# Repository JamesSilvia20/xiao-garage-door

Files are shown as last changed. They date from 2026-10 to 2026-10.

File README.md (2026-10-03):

# XIAO Garage Door 🚗🏠

**Make your garage door opener smart for about $10 in parts.** This is a tiny open-source board that holds a [Seeed Studio XIAO ESP32-C6](https://www.seeedstudio.com/Seeed-Studio-XIAO-ESP32C6-p-5884.html) and wires to your opener's wall-button terminals. You can then open and close your garage from **Home Assistant**, **Apple Home** (with Siri and automations), or anything else that talks to [ESPHome](https://esphome.io).

No cloud, no subscription, no app from the opener company. Everything runs on your own network.

<p align="center">
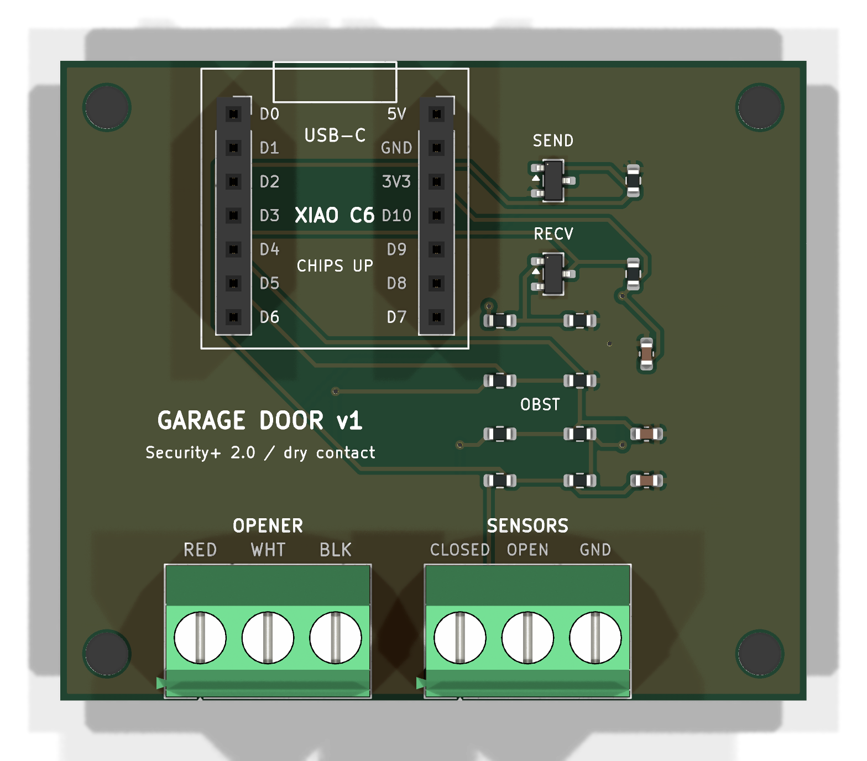
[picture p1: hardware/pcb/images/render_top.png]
XIAO Garage Door PCB
  
</p>

## What it does

| Your opener | What you get |
|---|---|
| **Security+ 2.0** (LiftMaster / Chamberlain / Craftsman with a **yellow** learn button, the myQ kind) | Real open / closed / opening / closing status, light, lock, obstruction alerts and motion, read straight from the opener. |
| **Security+ 1.0** (same brands, **purple / red / orange** learn button) | Same as above. |
| **Any opener with a simple 2-wire wall button** (most other brands, older units) | Open / close / stop from your phone. Add a $5 magnetic reed switch for true open/closed status. |

One board does all of these. You pick the matching firmware.

## Start here 👇

New to this? Follow the guides in order. They're written for complete beginners, and we explain every step.

1. 🔍 [**Which opener do I have?**](docs/start/which-opener.md): pick your firmware in 2 minutes.
2. 🛒 [**Parts and cost**](docs/start/parts.md): everything you need, with links.
3. ⚠️ [**Safety first**](docs/start/safety.md): please read this one.
4. 🔧 Get the hardware, either way:
   - [**Order the ready-made PCB**](docs/hardware/order-pcb.md) from JLCPCB or PCBWay, all parts soldered for you, about $25–40 for 5 boards; **or**
   - [**Build it on perfboard**](docs/hardware/perfboard.md) with a few cheap parts (new to soldering? see [**Soldering 101**](docs/hardware/soldering-101.md)).
5. ⚡ [**Flash the firmware**](docs/setup/flash.md): straight from your web browser, no software to install.
6. 🏠 [**Add to Home Assistant**](docs/setup/home-assistant.md) and [**Apple Home**](docs/setup/apple-home.md).
7. 🪛 [**Install it at the opener**](docs/setup/install.md).

Stuck? See [**Troubleshooting**](docs/help/troubleshooting.md) and the [**FAQ**](docs/help/faq.md).

> [!TIP]
> Prefer a website? The same guides are at **https://jamessilvia20.github.io/xiao-garage-door/**, and that's where the one-click **browser installer** lives.

## What's in this repo

```
firmware/        ESPHome configs (one per opener type) - flash from the browser or adopt in ESPHome
hardware/pcb/    The PCB: KiCad board, scripts that build it, and ready-to-upload JLCPCB / PCBWay files
docs/            All the tutorials (this is also the website)
```

## Project status

Honest status, so you know what's been tested:

| Part | Status |
|---|---|
| Dry-contact firmware + hand-built perfboard | ✅ Built and bench-tested by the author (switches the wall-button contacts on command, shows up in HA and Apple Home). |
| Security+ 2.0 / 1.0 firmware | ✅ Compiles for the XIAO C6, using the proven [esphome-ratgdo](https://github.com/ratgdo/esphome-ratgdo) component and the community [rat-ratgdo](https://github.com/Kaldek/rat-ratgdo) circuit. 🧪 Not yet tested by the author on this exact board. Reports welcome! |
| PCB v1 | 🧪 Design passes KiCad DRC with 0 errors, and the JLCPCB/PCBWay files are generated. First boards are on order. |

Built one? Please open an issue or discussion with how it went (photos welcome!), so we can turn the 🧪s into ✅s.

## Credits

This stands on the shoulders of [**ratgdo**](https://github.com/ratgdo) (Paul Wieland and contributors), [**rat-ratgdo**](https://github.com/Kaldek/rat-ratgdo), [**esphome-ratgdo**](https://github.com/ratgdo/esphome-ratgdo), [**ESPHome**](https://esphome.io) and [**Home Assistant**](https://www.home-assistant.io). If you want a polished, ready-made product, buy an official [ratgdo](https://ratcloud.llc). It's great and supports the people who figured all this out.

See [Credits and license](docs/makers/credits.md).

## License

[MIT](LICENSE) for everything in this repo (firmware configs, PCB, docs). The Security+ firmware pulls in esphome-ratgdo, which is GPL-2.0.

> [!WARNING]
> Garage doors are heavy and can hurt people. Keep your photo-eye safety sensors connected and working. Never close the door remotely unless you can be sure nobody is under it. See [Safety first](docs/start/safety.md).

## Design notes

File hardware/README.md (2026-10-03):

# Hardware

| Folder | What's inside |
|---|---|
| [`pcb/jlcpcb/`](pcb/jlcpcb) | Ready-to-upload JLCPCB files: Gerbers zip, BOM, CPL |
| [`pcb/pcbway/`](pcb/pcbway) | PCBWay files: Gerbers zip, BOM (manufacturer part numbers), centroid |
| [`pcb/source/`](pcb/source) | KiCad board + the Python scripts that generate, route and check it |
| [`pcb/images/`](pcb/images) | Renders |

**Guides:** [Order the PCB](../docs/hardware/order-pcb.md) · [Build on perfboard](../docs/hardware/perfboard.md) · [How the circuit works](../docs/hardware/circuit.md) · [Edit the PCB](../docs/makers/edit-pcb.md)

PCB

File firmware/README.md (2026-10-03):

# Firmware

ESPHome configs for the Seeed XIAO ESP32-C6 on the XIAO Garage Door board (or the perfboard build).

| Config | Opener |
|---|---|
| [`garage-secplus2.yaml`](garage-secplus2.yaml) | Security+ 2.0, yellow learn button (myQ) |
| [`garage-secplus1.yaml`](garage-secplus1.yaml) | Security+ 1.0, purple / red / orange learn button |
| [`garage-dry-contact.yaml`](garage-dry-contact.yaml) | Simple 2-wire wall button, no sensor (assumed state) |
| [`garage-dry-contact-sensor.yaml`](garage-dry-contact-sensor.yaml) | Simple 2-wire wall button + reed switch (real state) |

No Wi-Fi passwords or keys are baked in. Set Wi-Fi with the browser installer (Improv) or the "Garage Door Setup" hotspot.

**Flash:** see [Flash the firmware](../docs/setup/flash.md). **Reference:** [Firmware reference](../docs/makers/firmware.md).

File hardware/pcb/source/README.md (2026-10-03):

# PCB source

Generated with KiCad 10's Python API and autorouted with freerouting. See [Edit the PCB](../../../docs/makers/edit-pcb.md) for how to rebuild.

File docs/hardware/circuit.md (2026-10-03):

# How the circuit works

Circuit

The board has four small blocks:

## 1. Send: "press" the button

**Q1 (AO3400A)** is an electronic switch between the **RED** wire and ground.

- **Dry-contact openers:** when the XIAO sets **D2** high for half a second, Q1 connects RED to ground. That's exactly what pressing the wall button does.
- **Security+ openers:** the same switch sends the data bits by pulling RED low very quickly. The red wire idles at about 12 V and the opener reads these pulses.

**R1 (10 kΩ)** holds Q1 **off** while the XIAO boots, so the door can't twitch during power-up.

## 2. Receive (Security+ only)

The opener sends its status (door position, light, lock, obstruction) back on the same RED wire. **Q2 (2N7002)** turns the 12 V signal into a safe 3.3 V signal on **D3**:
- RED high → Q2 on → D3 reads **low**;
- RED low → D3 reads **high**, through the R2 pull-up.

The signal is inverted, and the firmware expects that. **R3 (1 kΩ)** protects the gate, and **R4 (100 kΩ)** keeps Q2 off when nothing is connected.

## 3. Obstruction (Security+ only)

The **BLACK** wire carries the photo-eye signal. **R5/R6** halve it so the XIAO's **D5** never sees more than 3.3 V (as long as BLACK stays under about 7 V; we check this when installing).

## 4. Door sensors (optional)

Two inputs (**CLOSED** → D4, **OPEN** → D1) for magnetic reed switches that short to GND.
- **R7/R8:** 10 kΩ pull-ups to 3V3.
- **R9/R10:** 1 kΩ series resistors to protect against long-wire zaps.
- **C1/C2:** 100 nF to filter noise.

The dry-contact firmware uses CLOSED for real open/closed status. The Security+ firmware uses them as optional external open/close trigger inputs.

## Why these pins?

| Pin | Use | Notes |
|---|---|---|
| D2 (GPIO2) | Send | A safe general-purpose pin |
| D3 (GPIO21) | Receive | |
| D5 (GPIO23) | Obstruction | |
| D4 (GPIO22) | CLOSED sensor | |
| D1 (GPIO1) | OPEN sensor | |
| **D6 (GPIO16)** | **avoided** | It's the C6's boot serial output and would pulse the door wire every boot. |
| GPIO 8, 9, 15 | **avoided** | Strapping pins |
| GPIO 3 / 14 | (used internally) | The XIAO C6's antenna switch; the firmware selects the built-in antenna. |

## Where it came from

The send / receive / obstruction circuit is the community [rat-ratgdo](https://github.com/Kaldek/rat-ratgdo) design (MIT), adapted to the XIAO ESP32-C6. The Security+ protocol handling is [esphome-ratgdo](https://github.com/ratgdo/esphome-ratgdo).

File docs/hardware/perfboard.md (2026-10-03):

# Build it on perfboard

No PCB order? You can build the same circuit by hand on a piece of perfboard. Never soldered? Read [Soldering 101](soldering-101.md) first. It takes 15 minutes and saves a lot of frustration.

> [!TIP]
> **Dry-contact openers** need only **one transistor and one resistor**, a great first soldering project. **Security+ openers** need the full circuit, including one tiny surface-mount part. If that sounds scary, the [ready-made PCB](order-pcb.md) is the easy way.

## Know your XIAO pins first

This is where most mistakes happen. Several pins sit right next to each other, and mixing up GND and 3V3 is very easy (we did it 😅).

Hold the XIAO **chips facing you, USB-C at the top**:

```
              USB-C
        ┌───────────────┐
   D0   │ ●           ● │  5V
   D1   │ ●           ● │  GND   ← 2nd pin from the USB end
   D2   │ ●           ● │  3V3   ← 3rd pin from the USB end (NOT ground!)
   D3   │ ●           ● │  D10
   D4   │ ●           ● │  D9
   D5   │ ●           ● │  D8
   D6   │ ●           ● │  D7
        └───────────────┘
```

**Golden rule: count from the USB-C end.** It works whichever way you're looking at the board, front or back.
- **D2** = 3rd pin from the USB end, in the **D0–D6** column.
- **GND** = 2nd pin from the USB end, in the **5V / GND / 3V3** column.

> [!WARNING]
> On the **back** of the board everything is mirrored left-right. Before you flip it over, put a marker dot next to the holes you'll solder.

**Foolproof GND check:** with the multimeter on continuity (beep), touch the **metal shell of the USB-C port** (that's ground) and then the pin. **GND beeps; 3V3 does not.**

## Dry-contact build (old / simple openers)

### Parts
1 × 2N7000, 1 × 10 kΩ resistor, perfboard, a 2- or 3-pin screw terminal (or two wires), and short pieces of solid wire.

### The 2N7000's legs

Hold it with the **flat side (the printing) facing you** and the **legs pointing down**:

```
   ┌─────────┐
   │  flat   │
   └─┬──┬──┬─┘
   LEFT MID RIGHT
   (S)  (G)  (D)
```

### Wiring: 5 connections

| From | To | Why |
|---|---|---|
| XIAO **D2** | 2N7000 **middle** leg | The "press" signal |
| 10 kΩ resistor | between 2N7000 **middle** leg and **GND** | Keeps it off while the XIAO boots |
| 2N7000 **left** leg | **GND** | |
| 2N7000 **right** leg | terminal **slot 1** | Goes to the opener's wall-button **+** |
| XIAO **GND** | terminal **slot 2** | Goes to the wall-button **common** |

Nothing connects to **3V3** or **5V**.

### Check before powering (USB unplugged, meter on continuity)

These should **beep**:
- [ ] D2 ↔ 2N7000 middle leg
- [ ] 2N7000 left leg ↔ terminal slot 2 ↔ **USB-C metal shell**
- [ ] 2N7000 right leg ↔ terminal slot 1

These must **not** beep:
- [ ] Any two legs of the 2N7000
- [ ] D2 ↔ GND
- [ ] GND ↔ 3V3, and GND ↔ 5V
- [ ] Any two neighbouring XIAO pins (solder bridges love to hide here)

### Check it switches (after flashing)

1. Meter on **DC volts**, black probe on the **USB-C shell**, red probe on the 2N7000 **middle leg**. Press the door button in Home Assistant: it should read about **0 V at rest** and **3.3 V during the press**.
2. Meter on **continuity**, across **slot 1 and slot 2**: **silent** at rest, **beeps** during a press.

> [!NOTE]
> At rest the meter may beep in **one** probe direction only. That's the transistor's built-in diode, and it's normal. It should be silent the other way round.

## Security+ build (LiftMaster / Chamberlain with a learn button)

This is the full circuit from [How the circuit works](circuit.md), the same as the PCB but with a 2N7000 instead of the 2N7002:

| Block | Connections |
|---|---|
| **Send** | D2 → AO3400A **gate**; 10 kΩ gate→GND; AO3400A **source**→GND; AO3400A **drain** → **RED** terminal |
| **Receive** | 2N7000 **drain** → D3; 10 kΩ from D3 → **3V3**; 2N7000 **source** → GND; 2N7000 **gate** → 1 kΩ → **RED**; 100 kΩ gate→GND |
| **Obstruction** | **BLACK** terminal → 10 kΩ → D5; 10 kΩ D5→GND |
| **Ground** | XIAO GND → **WHITE** terminal |

**AO3400A pins (SOT-23):** pin 1 = gate, pin 2 = source, pin 3 = drain (the single pin on its own side). Solder it onto a **SOT-23 to DIP adapter** first:
1. Tin one pad.
2. Hold the chip with tweezers and reheat that pad.
3. Solder the other two legs with a tiny bit of solder each.

Then check pin 1 against the adapter's marking.

## Next

[Flash the firmware →](../setup/flash.md)

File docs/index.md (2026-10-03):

# XIAO Garage Door

**Make your garage door opener smart for about $10 in parts.** A tiny open-source board holds a Seeed Studio XIAO ESP32-C6 and wires to your opener's wall-button terminals. Then you can open and close your garage from **Home Assistant**, **Apple Home** (with Siri and automations), or anything that talks to ESPHome. No cloud, no subscription.

XIAO Garage Door PCB

## Works with

| Your opener | What you get |
|---|---|
| **Security+ 2.0** (LiftMaster / Chamberlain / Craftsman, **yellow** learn button, myQ) | Real status from the opener: open / closed / opening / closing, light, lock, obstruction, motion. |
| **Security+ 1.0** (same brands, **purple / red / orange** learn button) | Same as above. |
| **Any opener with a simple 2-wire wall button** | Open / close / stop. Add a reed switch for real status. |

## Follow the guides in order

1. [Which opener do I have?](start/which-opener.md)
2. [Parts and cost](start/parts.md)
3. [Safety first](start/safety.md)
4. Get the hardware: [order the ready-made PCB](hardware/order-pcb.md) **or** [build it on perfboard](hardware/perfboard.md) ([Soldering 101](hardware/soldering-101.md))
5. [Flash the firmware](setup/flash.md) using the [browser installer](install/index.md)
6. [Add to Home Assistant](setup/home-assistant.md) and [Apple Home](setup/apple-home.md)
7. [Install it at the opener](setup/install.md)

Stuck? See [Troubleshooting](help/troubleshooting.md) and the [FAQ](help/faq.md).

> [!NOTE]
> Everything here lives in the [GitHub repo](https://github.com/JamesSilvia20/xiao-garage-door). These pages are the same Markdown files you can read right on GitHub.

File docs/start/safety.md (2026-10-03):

# Safety first ⚠️

A garage door weighs 70–200 kg (150–400 lb). Please take these seriously.

- **Keep the photo-eye safety sensors connected and working.** Never bypass them. The opener reverses when the beam is broken. That's your main protection, and this project doesn't change it.
- **Remote closing is risky.** Don't make automations that close the door when nobody can see it, unless the opener flashes and beeps before moving (many newer openers do this by themselves).
- **Unplug the opener before connecting wires** to its terminals. The low-voltage terminals are safe, but the opener has 120/230 V inside. Don't open the motor cover.
- **Measure before you connect.** Check the wall-button / wall-control voltage with a multimeter first ([Install at the opener](../setup/install.md) shows how). Our board is designed for the low-voltage DC found on these terminals (about 5–24 V). If you see AC or anything higher, stop and ask.
- **Test the door's auto-reverse** once a month: put a 2×4 flat on the floor under the door and close it. The door must reverse when it touches the board.
- **Kids:** don't put a garage button where small children can reach it in an app or widget.

> [!CAUTION]
> This is a hobby project, provided as-is with no warranty (see the [license](https://github.com/JamesSilvia20/xiao-garage-door/blob/main/LICENSE)). You're responsible for installing it safely.

Next: get the hardware, either [order the ready-made PCB](../hardware/order-pcb.md) or [build it on perfboard](../hardware/perfboard.md).

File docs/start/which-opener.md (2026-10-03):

# Which opener do I have?

This decides which firmware you flash. The board is the same for all of them.

## 1. Find the "learn" button

Get on a step ladder and look at the opener motor unit on the ceiling. There's usually a small square **LEARN** button near the antenna wire, often under the light cover, with a small LED next to it. **Note its color.**

| Learn button color | Protocol | Firmware |
|---|---|---|
| **Yellow** | Security+ 2.0 (most LiftMaster / Chamberlain / Craftsman from about 2011 on, anything "myQ") | `garage-secplus2` |
| **Purple**, **red/orange** | Security+ 1.0 | `garage-secplus1` |
| **Green** | Billion Code (very old Chamberlain). Uses a plain wall button. | `garage-dry-contact` |
| **No learn button**, or another brand (Genie, Overhead Door, Linear, Ryobi, Skylink…) | Usually a simple 2-wire wall button | `garage-dry-contact` |

## 2. Check the wall button

Look at the button on the wall by the door into the house.

- **A plain doorbell-style button** with 2 thin wires usually means a **dry-contact** opener. Our test is in step 3.
- **A wall panel with several buttons** (light, lock, motion) on a LiftMaster or Chamberlain is **Security+** (2.0 or 1.0, by the learn button color).

> [!IMPORTANT]
> Some brands use "smart" wall buttons that send data, not a simple contact. If you're unsure, do the test below **before** buying anything.

## 3. The 30-second dry-contact test

With the opener plugged in, **briefly touch a short wire across the two wall-button terminals** on the back of the opener.

- **The door moves:** it's a dry-contact opener. ✅ Use `garage-dry-contact`.
- **Nothing happens:** it's a data-type wall control. Check the learn button color again, or ask in the [discussions](https://github.com/JamesSilvia20/xiao-garage-door/discussions) with a photo of your opener's label.

> [!TIP]
> Never done this before? The terminals are the screws or push-in slots where the wall-button wires connect, usually labelled with colors or numbers. The voltage there is low (usually 5–24 V DC) and safe to touch, but keep your fingers off the 120 V wiring inside the opener.

## Not sure? Take a photo

Take a photo of the opener's **label** (model number) and the **wall button**, and open a [discussion](https://github.com/JamesSilvia20/xiao-garage-door/discussions). Someone can tell you.

Next: [Parts and cost →](parts.md)

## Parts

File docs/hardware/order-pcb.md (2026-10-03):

# Order the ready-made PCB

A board house builds and assembles the board for you: all the small parts, the XIAO sockets and the screw terminals. When it arrives you **just plug in your XIAO**. No soldering at all.

| Top | Bottom |
|---|---|
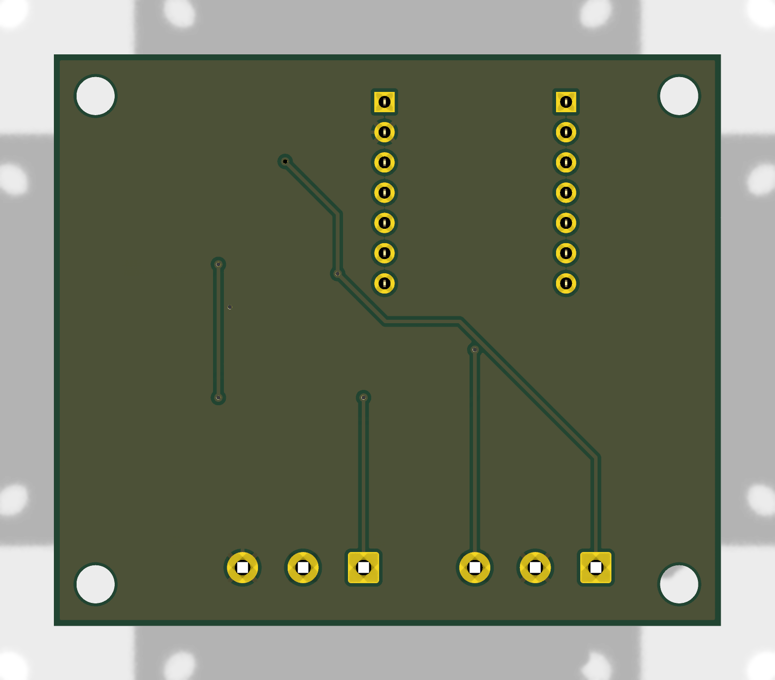
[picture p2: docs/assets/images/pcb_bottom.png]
PCB bottom
| PCB top |  |

**Board:** 56 × 48 mm, 2 layers, 4 × M3 mounting holes.

## Download the files

| File | What it is |
|---|---|
| [`garage_door_gerbers.zip`](https://github.com/JamesSilvia20/xiao-garage-door/raw/main/hardware/pcb/jlcpcb/garage_door_gerbers.zip) | The board itself (Gerbers + drill files). Upload this first. |
| [`garage_door_bom.csv`](https://github.com/JamesSilvia20/xiao-garage-door/raw/main/hardware/pcb/jlcpcb/garage_door_bom.csv) | JLCPCB parts list (with LCSC part numbers) |
| [`garage_door_cpl.csv`](https://github.com/JamesSilvia20/xiao-garage-door/raw/main/hardware/pcb/jlcpcb/garage_door_cpl.csv) | JLCPCB placement file |
| [`garage_door_bom_pcbway.csv`](https://github.com/JamesSilvia20/xiao-garage-door/raw/main/hardware/pcb/pcbway/garage_door_bom_pcbway.csv) | PCBWay parts list (manufacturer part numbers) |
| [`garage_door_centroid_pcbway.csv`](https://github.com/JamesSilvia20/xiao-garage-door/raw/main/hardware/pcb/pcbway/garage_door_centroid_pcbway.csv) | PCBWay placement file |

## Option 1: JLCPCB (exact price right away)

1. Go to **[jlcpcb.com](https://jlcpcb.com)** → **Instant Quote**, and upload **`garage_door_gerbers.zip`**. It should detect **2 layers, 56 × 48 mm**. Leave everything else on the defaults; any color is fine.
2. Scroll down and switch **PCB Assembly** **on**.
   - **PCBA Type:** Economic
   - **Assembly Side:** Top
   - **PCBA Qty:** 2 or 5 (5 gives spares for friends)
3. Click **Next**, then sign in (or make a free account).
4. Upload **`garage_door_bom.csv`** (BOM) and **`garage_door_cpl.csv`** (CPL), then click **Process BOM & CPL**.
5. **Check the parts list.** All 10 lines should match:

   | Designator | Part | LCSC |
   |---|---|---|
   | C1–C3 | 100 nF | C14663 |
   | J1, J2 | Screw terminal 3P 5.08 mm | C474953 |
   | J3, J4 | Female header 1×7 2.54 mm (XIAO sockets) | C2932672 |
   | Q1 | AO3400A | C20917 |
   | Q2 | 2N7002 | C8545 |
   | R1, R2, R5–R8 | 10 kΩ | C25804 |
   | R3, R9, R10 | 1 kΩ | C21190 |
   | R4 | 100 kΩ | C25803 |

   > [!IMPORTANT]
   > JLCPCB may leave **J1–J4 unticked** with a ⚠️ saying "multiple lines matched the same part". That's expected, because the two terminals share one part and the two sockets share another. **Tick all four** or your board arrives without sockets and terminals.

6. **Check the placement preview.** The two small 3-pin transistors (**Q1** near "SEND", **Q2** near "RECV") must have their pin-1 dot on the side with **two** pins, matching the white dot on the board. If one looks spun around, rotate it 180° in the preview. JLCPCB's engineers also check this after you order.
7. Pick a **Product Description** for customs (for example "DIY / hobby"), **Save to Cart**, choose shipping, and pay.

**Example price (Oct 2026):** $4 for the boards + about $20 assembly = **about $24**, plus shipping.

## Option 2: PCBWay (price after review)

1. Go to **[pcbway.com](https://www.pcbway.com)** → **PCB Assembly**, and enter **Quantity 5, Unique parts 8, SMD parts 15, Thru-holes 4**. Click **Quote & Order**.
2. Keep **Turnkey** (PCBWay buys the parts), Single pieces, Top side, then **Save to Cart** (sign in).
3. In the upload box: Gerbers = **`garage_door_gerbers.zip`**, BOM = **`garage_door_bom_pcbway.csv`**, Centroid = **`garage_door_centroid_pcbway.csv`**. Click **Submit**.
4. PCBWay reviews the files (usually within 1–2 days) and emails the final price, including the board and parts. Nothing is charged until you pay.

**Example estimate (Oct 2026):** $29 assembly + board + parts, with shipping discounted. That came to **about $40 total**.

## When it arrives

1. **Check the XIAO orientation:** the board shows the outline. **USB-C faces the top edge, chips face up.**
2. Push the XIAO (with its pins) into the two sockets.
3. Go to [Flash the firmware →](../setup/flash.md)

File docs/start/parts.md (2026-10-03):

# Parts and cost

## Everyone needs

| Part | Approx. cost | Notes |
|---|---|---|
| **Seeed Studio XIAO ESP32-C6** | $5–7 | Buy it **with pins** (headers), or solder them on yourself. One per door. |
| **USB-C cable + any 5 V USB charger** | (you probably have one) | Powers the board. Plug it into the outlet the opener uses. Some cables only charge, so use one that also carries **data** for flashing. |
| **2–3 wires** | (anything thin) | From the board to the opener's terminals. 22 AWG doorbell or thermostat wire is perfect. |
| **A multimeter** | $10–20 | Very helpful for checking voltages and your soldering. |

## Then pick ONE way to get the board

### Option A: ready-made PCB (no tiny soldering) ⭐ recommended

JLCPCB or PCBWay makes and assembles the board. You just plug in the XIAO.

| | Cost | Time |
|---|---|---|
| 5 assembled boards (JLCPCB, example quote) | about $25 + shipping (~$10–30) | about 1–2 weeks |
| 5 assembled boards (PCBWay, example quote) | about $40 shipped, final price after their review | about 1–2 weeks |

That's enough boards for you plus a few friends. See [Order the ready-made PCB](../hardware/order-pcb.md).

### Option B: build it on perfboard (cheapest, you solder)

**Dry-contact openers** only need:

| Part | Qty | Example |
|---|---|---|
| 2N7000 MOSFET (TO-92) | 1 | DigiKey 2N7000, or any electronics kit |
| 10 kΩ resistor | 1 | brown-black-orange |
| Perfboard (2.54 mm) | 1 small piece | |
| 2- or 3-pin 5.08 mm screw terminal (optional) | 1 | or solder wires directly |

**Security+ openers** also need:

| Part | Qty | Notes |
|---|---|---|
| AO3400A MOSFET (SOT-23) + SOT-23 to DIP adapter | 1 each | Tiny! The adapter makes it solderable. |
| 2N7000 | 1 | (instead of the 2N7002 on the PCB) |
| 10 kΩ resistors | 4 | |
| 1 kΩ resistor | 1 | |
| 100 kΩ resistor | 1 | |

See [Build it on perfboard](../hardware/perfboard.md).

## Optional: real open/closed status for dry-contact openers

| Part | Cost | Notes |
|---|---|---|
| **Wired magnetic reed switch** (garage-door type, normally open) | $5–12 | Mounts on the floor or track, and closes when the door is fully closed. Wires to SENSORS **CLOSED** + **GND**. |

Next: [Safety first →](safety.md)

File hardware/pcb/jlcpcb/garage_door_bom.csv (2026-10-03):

Comment | Designator | Footprint | LCSC Part #
100nF | C1,C2,C3 | C_0603_1608Metric | C14663
OPENER | J1 | TerminalBlock_Phoenix_MKDS-1,5-3-5.08_1x03_P5.08mm_Horizontal | C474953
SENSORS | J2 | TerminalBlock_Phoenix_MKDS-1,5-3-5.08_1x03_P5.08mm_Horizontal | C474953
XIAO L | J3 | PinSocket_1x07_P2.54mm_Vertical | C2932672
XIAO R | J4 | PinSocket_1x07_P2.54mm_Vertical | C2932672
AO3400A | Q1 | SOT-23 | C20917
2N7002 | Q2 | SOT-23 | C8545
10k | R1,R2,R5,R6,R7,R8 | R_0603_1608Metric | C25804
1k | R3,R9,R10 | R_0603_1608Metric | C21190
100k | R4 | R_0603_1608Metric | C25803

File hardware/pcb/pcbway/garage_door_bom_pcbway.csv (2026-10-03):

Item # | Designator | Qty | Manufacturer | Mfg Part # | Description / Value | Package/Footprint | Type
1 | C1,C2,C3 | 3 | YAGEO | CC0603KRX7R9BB104 | 100nF 50V X7R 0603 capacitor | 0603 | SMD
2 | R1,R2,R5,R6,R7,R8 | 6 | UNI-ROYAL | 0603WAF1002T5E | 10k 1% 0603 resistor | 0603 | SMD
3 | R3,R9,R10 | 3 | UNI-ROYAL | 0603WAF1001T5E | 1k 1% 0603 resistor | 0603 | SMD
4 | R4 | 1 | UNI-ROYAL | 0603WAF1003T5E | 100k 1% 0603 resistor | 0603 | SMD
5 | Q1 | 1 | Alpha & Omega | AO3400A | N-MOSFET 30V 5.7A | SOT-23 | SMD
6 | Q2 | 1 | CJ (Jiangsu Changjing) | 2N7002 | N-MOSFET 60V 115mA | SOT-23 | SMD
7 | J1,J2 | 2 | Cixi Kefa | KF128-5.08-3P | Screw terminal 3P 5.08mm (LCSC C474953) | THT P5.08 | THT
8 | J3,J4 | 2 | Kinghelm | KH-2.54FH-1X7P-H8.5 | Female header 1x7 2.54mm 8.5mm (LCSC C2932672) | THT P2.54 | THT

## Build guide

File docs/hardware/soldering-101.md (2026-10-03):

# Soldering 101 (for total beginners)

Never soldered before? Neither had the person who built the first one of these. Here's everything that tripped us up.

## Safety

- The iron tip is about **350 °C**. Always put it back in its stand.
- Work with some airflow; don't breathe the flux smoke.
- Wash your hands after handling solder.
- Wear glasses, because solder can flick.

## Your iron

- **A temperature-controlled iron** (for example a Pinecil, ~$30) heats up in seconds and makes life easy.
- **A basic plug-in iron** (for example a 25 W Weller) works for perfboard, but needs **3–5 minutes** to heat up.
- **"It takes forever to melt solder"** almost always means the tip isn't **tinned**. Melt solder straight onto the hot tip until the whole tip is shiny silver. Use the **side** of the tip, not the point.

**Flux-core solder is all you need.** Just add a little **fresh** solder to each joint, which brings fresh flux with it.

## Which side of the perfboard?

- **Parts go on the plain side.**
- **You solder on the side with the metal rings** around the holes.

If your board has metal rings on both sides, either side works.

## One joint, step by step

```
        leg (sticking up)
          |
   iron → |  ← solder
     _____|_____
    (  ring   )
```

1. Touch the iron so it touches **both the leg and the metal ring** at the same time. Hold 1–2 seconds.
2. Touch the solder to the **opposite side** of the leg, on the ring, not onto the iron.
3. Feed in about **3–5 mm** of solder. It flows around the leg.
4. Remove the solder, then the iron. **Don't move anything** for 3 seconds.
5. **A good joint is shiny and shaped like a small volcano.** A ball sitting on top means the ring wasn't hot enough; reheat with a touch of fresh solder.
6. Clip the extra leg.

## Connecting things on perfboard

Perfboard holes are **not connected to each other**. Every connection is either:
- a **bent leg** (bend a part's leg over to the next joint), or
- a **piece of solid wire** (the stiff breadboard jumper wires in most starter kits are perfect).

## Solder bridges (the #1 problem)

A **bridge** is solder accidentally joining two neighbouring pins. It causes very confusing symptoms; ours made a pin read 3.3 V all the time.

**Find them:** multimeter on continuity, test each pair of neighbouring pins. Neighbours should **not** beep (unless you connected them on purpose).

**Fix them:** wipe the tip clean, put it in the gap between the two pins, and **drag it away** from the part. The extra solder clings to the tip. If it won't let go, add a tiny bit of fresh solder (for the flux) and drag again.

## Cleaning the tip

- **While hot:** wipe on **brass wool** (best) or a **damp** sponge (damp, not wet), then re-tin immediately.
- **Black tip that won't take solder:** use **tip tinner** paste (~$8).
- **Don't use** sandpaper or files on the tip; it ruins the plating.
- Leave a blob of solder on the tip when you turn it off.

## The multimeter settings you'll use

| Setting | Symbol | Used for |
|---|---|---|
| **Continuity** | `)))` / 🔊 | Is it connected? A beep means yes. |
| **Ohms** | Ω | How connected? "OL" means open. |
| **DC volts** | V⎓ | Is the pin at 0 V or 3.3 V? |

The black probe goes in **COM**, the red probe in **VΩ** (not the 10 A jack). Touch the two probes together: continuity should beep.

Back to: [Build it on perfboard →](perfboard.md)

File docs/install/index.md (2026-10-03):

# Browser installer

Flash your XIAO ESP32-C6 straight from this page. Use **Chrome or Edge on a computer**; phones and Safari can't do it.

1. Plug the XIAO into your computer with a USB-C **data** cable.
2. Click the **Install** button for your opener type.
3. Pick the XIAO's serial port, then follow the prompts. At the end, enter your **Wi-Fi**.

Not sure which one? See [Which opener do I have?](../start/which-opener.md)

<script type="module" src="https://unpkg.com/esp-web-tools@10/dist/web/install-button.js?module"></script>

| Opener | Install |
|---|---|
| **Security+ 2.0**: yellow learn button (myQ) | <esp-web-install-button manifest="firmware/garage-secplus2.manifest.json"></esp-web-install-button> |
| **Security+ 1.0**: purple / red / orange learn button | <esp-web-install-button manifest="firmware/garage-secplus1.manifest.json"></esp-web-install-button> |
| **Dry contact**: simple 2-wire wall button | <esp-web-install-button manifest="firmware/garage-dry-contact.manifest.json"></esp-web-install-button> |
| **Dry contact + reed switch** | <esp-web-install-button manifest="firmware/garage-dry-contact-sensor.manifest.json"></esp-web-install-button> |

> [!NOTE]
> Reading this on GitHub? The Install buttons only work on the website: **https://jamessilvia20.github.io/xiao-garage-door/install/**. Or follow [Option B in the flashing guide](../setup/flash.md#option-b-from-github-using-esphome-web).

Problems? See [Flash the firmware → Troubleshooting](../setup/flash.md#troubleshooting-flashing).

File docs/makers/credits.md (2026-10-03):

# Credits and license

## Built on

- **[ratgdo](https://github.com/ratgdo)** by Paul Wieland and contributors: figured out how to talk to Security+ openers and made it open. Please consider buying an official [ratgdo](https://ratcloud.llc).
- **[esphome-ratgdo](https://github.com/ratgdo/esphome-ratgdo)** (GPL-2.0): the Security+ 1.0/2.0 ESPHome component used by the Security+ firmware here. It's pulled in at build time, not copied into this repo.
- **[rat-ratgdo](https://github.com/Kaldek/rat-ratgdo)** (MIT): the community DIY interface circuit this board's send/receive/obstruction blocks are based on.
- **[ESPHome](https://esphome.io)**, **[Home Assistant](https://www.home-assistant.io)**, **[KiCad](https://www.kicad.org)**, **[freerouting](https://github.com/freerouting/freerouting)**, **[ESP Web Tools](https://esphome.github.io/esp-web-tools/)** and **[MkDocs Material](https://squidfunk.github.io/mkdocs-material/)**.

## License

Everything in this repository (firmware configs, PCB design and scripts, documentation) is released under the **[MIT License](https://github.com/JamesSilvia20/xiao-garage-door/blob/main/LICENSE)**.

"LiftMaster", "Chamberlain", "Craftsman", "myQ" and "Security+" are trademarks of their owners. This project isn't affiliated with or endorsed by them.

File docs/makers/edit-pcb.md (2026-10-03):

# Edit the PCB

The board isn't hand-drawn. It's **generated by a Python script** with KiCad's scripting API, then autorouted with [freerouting](https://github.com/freerouting/freerouting). Change the script, rerun, and get fresh order files.

Files are in [`hardware/pcb/source/`](https://github.com/JamesSilvia20/xiao-garage-door/tree/main/hardware/pcb/source):

| File | What it does |
|---|---|
| `build_board.py` | Places every part, assigns nets, draws the outline and silkscreen |
| `route.py` | Exports to freerouting and imports the result, then adds the GND pours |
| `make.sh` | Runs everything: build → autoroute → pour → KiCad DRC |
| `export_jlc.py` | Writes the JLCPCB BOM and CPL with LCSC part numbers |
| `garage_door.kicad_pcb` | The finished board; open it in KiCad to look around |

## Requirements

- **KiCad 10.** On macOS the scripts expect it in `~/Applications/KiCad`; change the paths at the top of `make.sh` and `build_board.py` for other locations.
- **Java 25+** (for freerouting 2.x). On macOS: `brew install openjdk`.
- **freerouting.jar**, downloaded to `~/.cache/freerouting/freerouting.jar` from the [releases page](https://github.com/freerouting/freerouting/releases).

## Rebuild

```bash
cd hardware/pcb/source
./make.sh                       # build, route, pour, DRC -> drc.json
"$KICAD_PY" export_jlc.py        # BOM + CPL
kicad-cli pcb export gerbers --no-protel-ext -l F.Cu,B.Cu,F.Paste,B.Paste,F.Silkscreen,B.Silkscreen,F.Mask,B.Mask,Edge.Cuts -o gerbers/ garage_door.kicad_pcb
kicad-cli pcb export drill --format excellon --excellon-separate-th -o gerbers/ garage_door.kicad_pcb
```

Here `$KICAD_PY` is KiCad's bundled Python, for example `~/Applications/KiCad/KiCad.app/Contents/Frameworks/Python.framework/Versions/3.9/bin/python3` on macOS.

The last run had **0 unconnected items and 0 electrical errors**. The only warnings are the screw-terminal outlines touching the board edge, which is intended because they sit flush.

## Ideas for v2

- Onboard 12 V → 5 V regulator, to power from the opener's wall-control line (no USB charger needed)
- A status LED
- Relay output for openers that don't like transistor switching

PRs welcome!

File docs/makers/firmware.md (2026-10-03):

# Firmware reference

All firmware is plain [ESPHome](https://esphome.io) YAML in [`firmware/`](https://github.com/JamesSilvia20/xiao-garage-door/tree/main/firmware).

| File | Notes |
|---|---|
| `garage-secplus2.yaml` | Pulls in [esphome-ratgdo](https://github.com/ratgdo/esphome-ratgdo) `base.yaml` with this board's pins |
| `garage-secplus1.yaml` | Same, with `base_secplusv1.yaml` |
| `garage-dry-contact.yaml` | `time_based` cover with assumed state, plus a "Press Wall Button" button |
| `garage-dry-contact-sensor.yaml` | `template` cover whose state comes from the CLOSED reed switch |

## Pin map

| XIAO | GPIO | Function |
|---|---|---|
| D2 | GPIO2 | Send / press (Q1 gate) |
| D3 | GPIO21 | Receive (Q2 drain, inverted) |
| D5 | GPIO23 | Obstruction (BLACK through a ÷2 divider) |
| D4 | GPIO22 | SENSORS CLOSED |
| D1 | GPIO1 | SENSORS OPEN |
| (internal) | GPIO3, GPIO14 | Antenna switch, both held low (built-in antenna) |

## Substitutions you might change

| Name | Default | |
|---|---|---|
| `name` | `garage-door` | The device hostname gets a MAC suffix added |
| `friendly_name` | `Garage Door` | |
| `travel_time` | `13s` | Dry contact only: your door's full open time |

## Building the binaries yourself

```bash
pip install esphome
esphome compile firmware/garage-dry-contact.yaml
```

The prebuilt `.factory.bin` files used by the browser installer are in `docs/install/firmware/`. The GitHub Action in `.github/workflows/firmware.yml` compiles every config on each push.

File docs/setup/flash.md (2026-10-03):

# Flash the firmware

You only do this once. After that, updates go over Wi-Fi.

**Pick your firmware** (see [Which opener do I have?](../start/which-opener.md)):

| Firmware | For |
|---|---|
| `garage-secplus2` | Security+ 2.0, **yellow** learn button (myQ) |
| `garage-secplus1` | Security+ 1.0, **purple / red / orange** learn button |
| `garage-dry-contact` | Simple 2-wire wall button, no sensor |
| `garage-dry-contact-sensor` | Simple 2-wire wall button **plus** a reed switch on SENSORS CLOSED |

Plug the XIAO into your computer with a USB-C **data** cable. It doesn't need to be connected to the garage door yet.

## Option A: one-click browser installer (easiest)

Open the **[browser installer](https://jamessilvia20.github.io/xiao-garage-door/install/)** in **Chrome or Edge** on a computer, click your firmware's **Install** button, pick the XIAO's port, and follow the prompts. At the end it asks for your **Wi-Fi name and password**, and you're done.

## Option B: from GitHub, using ESPHome Web

1. Download your firmware's `.factory.bin` from the [latest release](https://github.com/JamesSilvia20/xiao-garage-door/releases/latest), or from [`docs/install/firmware/`](https://github.com/JamesSilvia20/xiao-garage-door/tree/main/docs/install/firmware).
2. Go to **[web.esphome.io](https://web.esphome.io)** in Chrome or Edge → **Connect** → pick the XIAO → **Install** → choose the `.bin` file.
3. When it finishes, click **⋮ → Configure Wi-Fi** and enter your Wi-Fi.

## Option C: ESPHome Device Builder (if you already use ESPHome)

Use one of the YAML files in [`firmware/`](https://github.com/JamesSilvia20/xiao-garage-door/tree/main/firmware) as your device config, or flash with option A and then click **Adopt** when it appears in your ESPHome dashboard. Adopting lets you customise it, for example the door's travel time.

## Setting Wi-Fi later

If the board can't reach your Wi-Fi, it makes its own hotspot called **"Garage Door Setup"**. Join it from your phone, and a page pops up where you pick your network.

## Troubleshooting flashing

- **The computer doesn't see the board:**
  - Use a different cable; many USB-C cables only charge.
  - Plug straight into the computer, not through a hub.
  - **Mac:** newer Macs ask **"Allow accessory to connect?"**. Click **Allow**. If you missed it, unplug and replug with the Mac unlocked.
- **Still nothing? Force download mode.** Hold the tiny **B** (BOOT) button on the XIAO, plug in the cable, then let go after 2 seconds.
- **It worked before, now it's invisible even in download mode:** look for a **solder bridge**, especially between **3V3 and a neighbouring pin**. See [Troubleshooting](../help/troubleshooting.md).

Next: [Add to Home Assistant →](home-assistant.md)

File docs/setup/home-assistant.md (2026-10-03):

# Add to Home Assistant

1. After flashing and setting Wi-Fi, Home Assistant usually finds it on its own. Go to **Settings → Devices & services**, look for **"Discovered: Garage Door"** under ESPHome, and click **Add**.
2. If it isn't discovered, click **Add integration → ESPHome** and enter `garage-door-xxxxxx.local` (the name shown in the installer) or the board's IP address.
3. Assign it to your **Garage** area.

## What you get

**Security+ firmware** (`garage-secplus2` / `garage-secplus1`):
- **Door** (cover): open / close / stop, with real position and opening/closing state
- **Light**, **Lock** (locks out remotes), **Obstruction**, **Motion**, **Button** presses, **Openings** count, and more

**Dry-contact firmware** (`garage-dry-contact`):
- **Door** (cover): open / close / stop. The position is **assumed** from the last command and the travel time.
- **Press Wall Button**: one press, exactly like the wall button.

**Dry-contact + sensor** (`garage-dry-contact-sensor`):
- **Door** (cover) with **real** open/closed status from the reed switch, and **Closed Sensor** / **Open Sensor**. Open/Close only press the button if the door isn't already there.

> [!WARNING]
> **Dry contact without a sensor:** single-button openers cycle **open → stop → close → stop**. If someone uses the wall button or a car remote, the door shown in HA can be wrong until the next command, and pressing "Close" could then actually open it. Add a reed switch (`garage-dry-contact-sensor`) to fix this for good.

## Set your door's travel time (dry contact only)

Time how long your door takes to open fully (for example 13 seconds). In ESPHome, adopt the device and change:

```yaml
substitutions:
  travel_time: 13s
```

## Example automation: notify if left open

```yaml
alias: Garage left open
triggers:
  - trigger: state
    entity_id: cover.garage_door_door
    to: open
    for: "00:15:00"
actions:
  - action: notify.notify
    data:
      message: "The garage door has been open for 15 minutes."
```

Next: [Add to Apple Home →](apple-home.md)

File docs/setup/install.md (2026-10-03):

# Install it at the opener

Read [Safety first](../start/safety.md) before this.

## 1. Measure (2 minutes, opener plugged in)

Set your multimeter to **DC volts (V⎓)** and measure across the opener's terminals:

| Opener type | Measure | Expect |
|---|---|---|
| **Security+** | **RED to WHITE** | about **12 V**, often flickering (that's the data) |
| **Security+** | **BLACK to WHITE** | about **7 V or less** (the 10k/10k divider brings it to ≤ 3.5 V) |
| **Dry contact** | across the **2 wall-button terminals** | steady **5–24 V DC**. Note which terminal is **+**: when the reading is positive, that's the one under the **red** probe. |

> [!CAUTION]
> If you see **AC volts**, a reading **over 24 V**, or (Security+) BLACK above about 7 V, **stop** and ask in the [discussions](https://github.com/JamesSilvia20/xiao-garage-door/discussions) before connecting.

## 2. Connect

1. **Unplug the opener.**
2. Run short wires from the board's **OPENER** terminal to the opener's terminals. Put them **alongside** the existing wall-button wires; don't remove those.

| Board OPENER terminal | Security+ opener | Dry-contact opener |
|---|---|---|
| **RED** | Red terminal | Wall-button **+** terminal |
| **WHT** | White terminal | Wall-button **common** (the other one) |
| **BLK** | Black terminal (photo-eye) | not used |

3. **Optional reed switch (dry-contact + sensor firmware):** wire it from **SENSORS CLOSED** to **SENSORS GND**. Mount it so it **closes when the door is fully closed**.
4. Mount the board near the opener: zip-tie it, use the 4 × M3 holes, or put it in a small case. Keep it away from the motor's moving parts.
5. Plug the opener back in, and power the XIAO from a USB charger in the opener's ceiling outlet.

## 3. Test

- **Security+:** in Home Assistant the door should show its real state within a few seconds. Toggle the **Light**, then try **Open** and **Close** while watching the door.
- **Dry contact:** press **Press Wall Button**. The door should start moving. Press again to stop it.
- **Finally:** test the safety reverse with a 2×4 on the floor under the door.

🎉 You're done! Enjoy asking Siri to close the garage.

Problems? → [Troubleshooting](../help/troubleshooting.md)

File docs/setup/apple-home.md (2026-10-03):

# Add to Apple Home

The board talks to Home Assistant. Home Assistant's **HomeKit Bridge** then shows it in Apple Home as a real **garage door** tile, with Siri ("Hey Siri, close the garage"), Control Center and automations.

## Easiest: from the HA screens

1. In Home Assistant: **Settings → Devices & services → Add integration → HomeKit Bridge**.
2. Choose **Accessory mode** and pick your garage door's **cover** entity (for example `cover.garage_door_door`).
   - Accessory mode gives the door its own Apple Home tile, just like a store-bought opener.
3. A **"HomeKit Pairing"** notification appears in HA with a QR code.
4. On your iPhone: **Home app → + → Add Accessory**, then scan that QR code. If it says "Uncertified Accessory", tap **Add Anyway**.
5. Pick a room.

## Or: YAML (if you already use `homekit:` in configuration.yaml)

```yaml
homekit:
  - name: Garage Door
    mode: accessory
    port: 21066            # any free port, different from your other HomeKit bridges
    filter:
      include_entities:
        - cover.garage_door_door
    entity_config:
      cover.garage_door_door:
        name: Garage Door
```

Restart Home Assistant, then pair from the notification as above.

## Notes

- Apple Home garage doors are **only open or closed**. There's no position slider, even on commercial openers.
- **Opening from outside the house** works through your Apple home hub (HomePod or Apple TV).
- Apple asks you to unlock your iPhone before opening a garage door. That's normal security.

Next: [Install it at the opener →](install.md)

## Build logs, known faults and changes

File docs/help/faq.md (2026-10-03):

# FAQ

**Does this replace my wall button and remotes?**
No. They all keep working. The board just adds a "virtual" wall button (and, on Security+, reads the opener's status).

**Does it need the internet or a cloud account?**
No. It runs locally on your Wi-Fi with Home Assistant. For Apple Home access from outside the house you need an Apple home hub (HomePod or Apple TV), like any HomeKit device.

**Can I use it without Home Assistant?**
The firmware is ESPHome, which is designed for Home Assistant. It also has a tiny built-in web page on Security+ builds. For native HomeKit with no Home Assistant, look at [homekit-ratgdo32](https://github.com/ratgdo/homekit-ratgdo32).

**Why a XIAO ESP32-C6?**
It's tiny, cheap (about $5), has Wi-Fi 6 and USB-C, and it **plugs into sockets**, so you can swap or reflash it easily.

**Can I open the door partway?**
Apple Home garage doors are open/closed only. Single-button (dry-contact) openers can't reliably stop at a position without a sensor, because each press cycles open → stop → close → stop.

**Is it safe?**
It's as safe as your wall button, as long as your **photo-eye sensors stay connected** and you follow [Safety first](../start/safety.md).

**How is this different from a ratgdo?**
It's the same idea and the same community circuit, adapted to a plug-in XIAO with fully open PCB files you can order yourself. If you want a finished, supported product, [buy a ratgdo](https://ratcloud.llc) and support the folks who made this possible.

**Can I change the PCB?**
Yes! The whole board is generated from a Python script. See [Edit the PCB](../makers/edit-pcb.md).

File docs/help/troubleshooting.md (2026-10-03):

# Troubleshooting

Real problems we hit while building these, and how we fixed them.

## The computer doesn't see the XIAO

| Cause | Fix |
|---|---|
| Charge-only USB-C cable | Use a cable that also carries data (the one from a phone or laptop). |
| Mac blocked the accessory | Click **Allow** on the "Allow accessory to connect?" popup. Replug with the Mac unlocked. |
| Firmware put the USB to sleep, or it's busy | Hold **B** (BOOT), plug in, release after 2 s. That's download mode, which always works on a healthy board. |
| **Solder bridge on the power pins** | If even download mode shows nothing, check for continuity between **3V3 and its neighbours** (GND, D10) and between **5V and GND**. Clear any bridge. |

## The switch is "on" all the time, or works backwards

Symptom: the opener terminals read as connected even when idle, or the transistor's gate reads 3.3 V while the button is off.

| Cause | How to check | Fix |
|---|---|---|
| **Wire on 3V3 instead of GND** (they're neighbours!) | Continuity from **terminal slot 2** to the **USB-C metal shell** must beep. | Move the wire one pin toward the USB end, to GND. |
| **D2 bridged to 3V3** | D2 ↔ 3V3 must not beep. | Clear the bridge. |
| **Wire on the wrong column** | D2 is the 3rd pin from the USB end in the **D0–D6** column. | Move it to the right column. |

## The meter beeps across the terminals at rest

If it beeps **only one way round**, that's the MOSFET's built-in body diode, and it's normal. Use the **Ω** setting: at rest it should read **OL** in at least one direction, and a low reading during a press.

## The door doesn't move when I press the button

1. Did the [dry-contact test](../start/which-opener.md#3-the-30-second-dry-contact-test) work (a wire across the wall-button terminals moves the door)? If not, your opener isn't dry-contact.
2. Is **RED** on the wall-button **+** terminal and **WHT** on the common? If they're swapped, the transistor can't switch.
3. Check the board's press with a meter (see [perfboard checks](../hardware/perfboard.md#check-it-switches-after-flashing)).

## Security+: "sync failed" notification, or no status

- Check the **RED / WHT / BLK** wiring matches the opener's terminals.
- Make sure you flashed the right protocol (yellow learn button = `secplus2`, purple/red/orange = `secplus1`).
- More help: the [esphome-ratgdo troubleshooting](https://github.com/ratgdo/esphome-ratgdo) docs apply directly.

## Apple Home shows the wrong state (dry contact, no sensor)

That's expected after someone uses the wall button or a remote: the board can only **assume** the position. Use **Press Wall Button** once to resync, or add a reed switch and switch to `garage-dry-contact-sensor`.

## Still stuck?

Open a [discussion](https://github.com/JamesSilvia20/xiao-garage-door/discussions) with:
- photos of **both sides** of your board;
- your opener's model;
- which firmware you flashed;
- what the multimeter shows.

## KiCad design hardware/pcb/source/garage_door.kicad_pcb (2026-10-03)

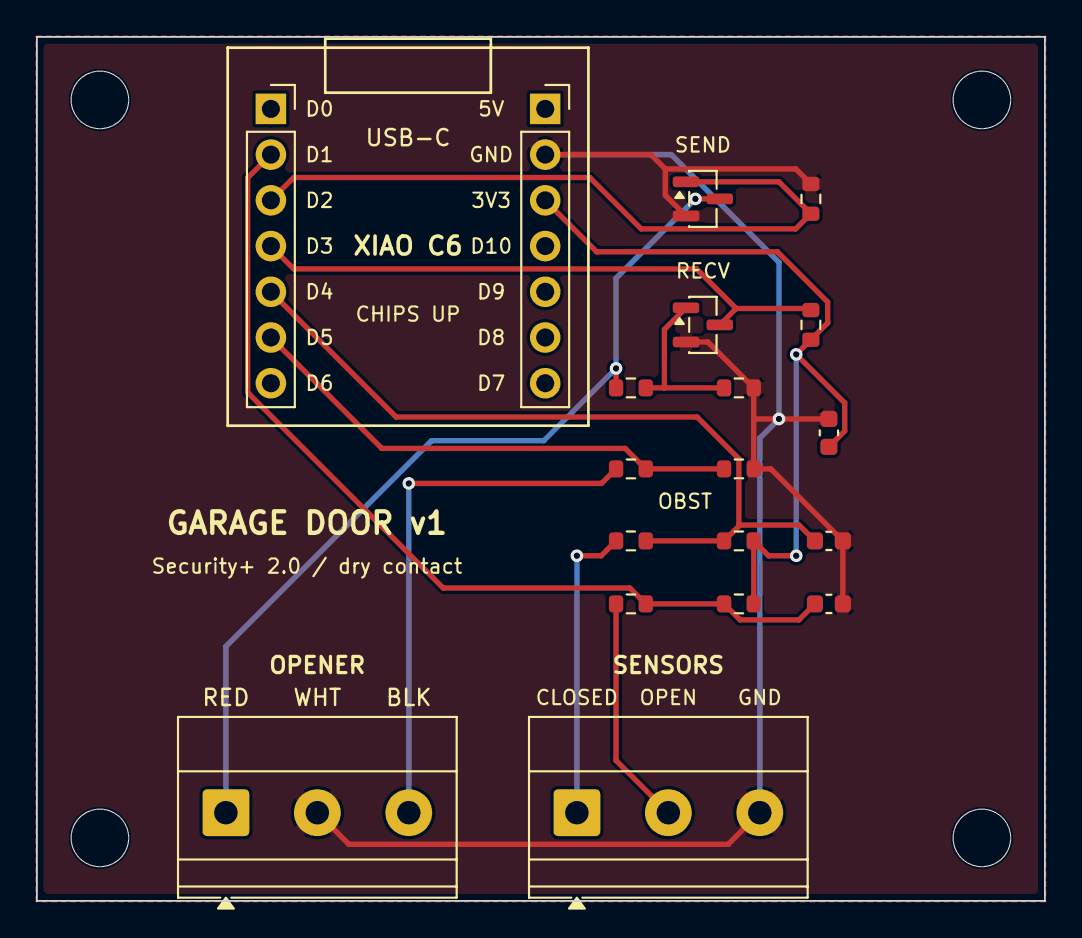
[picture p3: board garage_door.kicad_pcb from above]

Board: 2 copper layers, 56.0 x 48.0 mm, 23 parts (0 on the bottom side), 12 nets.

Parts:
C1, C2, C3: 100nF; C_0603_1608Metric
H1, H2, H3, H4: M3; MountingHole_3.2mm_M3
J1: OPENER; TerminalBlock_Phoenix_MKDS-1,5-3-5.08_1x03_P5.08mm_Horizont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
J2: SENSORS; TerminalBlock_Phoenix_MKDS-1,5-3-5.08_1x03_P5.08mm_Horizont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
J3: XIAO L; PinSocket_1x07_P2.54mm_Vertical
J4: XIAO R; PinSocket_1x07_P2.54mm_Vertical
Q1: AO3400A; SOT-23
Q2: 2N7002; SOT-23
R1, R2, R5, R6, R7, R8: 10k; R_0603_1608Metric
R3, R9, R10: 1k; R_0603_1608Metric
R4: 100k; R_0603_1608Metric

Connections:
+3V3: C3.1, J4.3, R2.1, R7.2, R8.2
BLACK: J1.3, R5.1
CLOSED: J2.1, R9.1
CLOSED_IN: C1.1, J3.5, R7.1, R9.2
GND: C1.2, C2.2, C3.2, J1.2, J2.3, J4.2, Q1.2, Q2.2, R1.2, R4.2, R6.2
OBST: J3.6, R5.2, R6.1
OPEN: J2.2, R10.1
OPEN_IN: C2.1, J3.2, R8.1, R10.2
RED: J1.1, Q1.3, R3.1
RX: J3.4, Q2.3, R2.2
RX_G: Q2.1, R3.2, R4.1
TX: J3.3, Q1.1, R1.1

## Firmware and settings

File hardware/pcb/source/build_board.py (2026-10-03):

"""Garage door carrier board for a Seeed XIAO ESP32-C6 (plugs into two 1x7 sockets).

One board for both doors:
  J1 OPENER  RED / WHITE / BLACK
     - Security+ 2.0 (MyQ LiftMaster): wire to the opener's red, white, black terminals.
     - Old "dumb" opener: RED -> wall-button +, WHITE -> wall-button common (BLACK unused).
  J2 SENSORS CLOSED / OPEN / GND  (reed switches to GND, optional)

XIAO pins (same as the hand-built boards):
  D2 GPIO2  -> Q1 AO3400A gate (send / press), R1 10k gate pull-down
  D3 GPIO21 <- Q2 2N7002 drain (receive, inverted), R2 10k pull-up; gate <- RED via R3 1k, R4 100k pull-down
  D5 GPIO23 <- BLACK via R5/R6 10k/10k divider (obstruction)
  D4 GPIO22 <- CLOSED via R9 1k, R7 10k pull-up, C1 100nF
  D1 GPIO1  <- OPEN   via R10 1k, R8 10k pull-up, C2 100nF

Run with KiCad's Python:  build_board.py  ->  garage_door.kicad_pcb (unrouted; see route.sh)
Coordinates in mm, KiCad frame (x right, y down). USB-C of the XIAO points to the top edge.
"""
import os
import pcbnew

HERE = os.path.dirname(os.path.abspath(__file__))
FP = os.path.expanduser('~/Applications/KiCad/KiCad.app/Contents/SharedSupport/footprints')
OUT = os.path.join(HERE, 'garage_door.kicad_pcb')

W, H = 56.0, 48.0           # board size
XL, XR = 13.0, 13.0 + 15.24  # XIAO socket columns
Y0 = 4.0                     # first XIAO pin (USB end)

board = pcbnew.CreateEmptyBoard()
board.SetCopperLayerCount(2)
mm = pcbnew.FromMM
nets = {}


def net(name):
    if name not in nets:
        n = pcbnew.NETINFO_ITEM(board, name)
        board.Add(n)
        nets[name] = n
    return nets[name]


def place(lib, name, ref, value, x, y, rot=0.0, lcsc=None, side_bottom=False):
    fp = pcbnew.FootprintLoad(os.path.join(FP, lib + '.pretty'), name)
    fp.SetReference(ref)
    fp.SetValue(value)
    fp.SetPosition(pcbnew.VECTOR2I(mm(x), mm(y)))
    fp.SetOrientationDegrees(rot)
    if lcsc:
        fp.SetField('LCSC', lcsc)
    board.Add(fp)
    return fp


def connect(fp, pad, netname):
    for p in fp.Pads():
        if p.GetNumber() == str(pad):
            p.SetNet(net(netname))
            return
    raise KeyError('%s pad %s' % (fp.GetReference(), pad))


def text(s, x, y, size=1.0, layer=pcbnew.F_SilkS, bold=False):
    t = pcbnew.PCB_TEXT(board)
    t.SetText(s)
    t.SetPosition(pcbnew.VECTOR2I(mm(x), mm(y)))
    t.SetLayer(layer)
    t.SetTextSize(pcbnew.VECTOR2I(mm(size), mm(size)))
    t.SetTextThickness(mm(size * (0.2 if bold else 0.15)))
    board.Add(t)


def line(x0, y0, x1, y1, layer=pcbnew.F_SilkS, w=0.15):
    s = pcbnew.PCB_SHAPE(board)
    s.SetShape(pcbnew.SHAPE_T_SEGMENT)
    s.SetStart(pcbnew.VECTOR2I(mm(x0), mm(y0)))
    s.SetEnd(pcbnew.VECTOR2I(mm(x1), mm(y1)))
    s.SetLayer(layer)
    s.SetWidth(mm(w))
    board.Add(s)


def rect(x0, y0, x1, y1, layer, w=0.15):
    for a, b, c, d in ((x0, y0, x1, y0), (x1, y0, x1, y1), (x1, y1, x0, y1), (x0, y1, x0, y0)):
        line(a, b, c, d, layer, w)


# ---------------------------------------------------------------- outline + holes
rect(0, 0, W, H, pcbnew.Edge_Cuts, 0.1)
for i, (x, y) in enumerate(((3.5, 3.5), (W - 3.5, 3.5), (3.5, H - 3.5), (W - 3.5, H - 3.5))):
    place('MountingHole', 'MountingHole_3.2mm_M3', 'H%d' % (i + 1), 'M3', x, y)

# ---------------------------------------------------------------- XIAO sockets
left = ['D0', 'D1', 'D2', 'D3', 'D4', 'D5', 'D6']          # USB end first
right = ['5V', 'GND', '3V3', 'D10', 'D9', 'D8', 'D7']
J3 = place('Connector_PinSocket_2.54mm', 'PinSocket_1x07_P2.54mm_Vertical', 'J3', 'XIAO L', XL, Y0, lcsc='C2932672')
J4 = place('Connector_PinSocket_2.54mm', 'PinSocket_1x07_P2.54mm_Vertical', 'J4', 'XIAO R', XR, Y0, lcsc='C2932672')
pin_net = {'D1': 'OPEN_IN', 'D2': 'TX', 'D3': 'RX', 'D4': 'CLOSED_IN', 'D5': 'OBST', 'GND': 'GND', '3V3': '+3V3'}
for i, n in enumerate(left):
    if n in pin_net:
        connect(J3, i + 1, pin_net[n])
for i, n in enumerate(right):
    if n in pin_net:
        connect(J4, i + 1, pin_net[n])

# ---------------------------------------------------------------- terminals (wire entry toward the bottom edge)
# Footprint body spans y -5.2..+4.6 around the pads, wire entry on +y: put the front flush with the edge.
TY = H - 4.9
J1X, J2X = 10.5, 30.0
J1 = place('TerminalBlock_Phoenix', 'TerminalBlock_Phoenix_MKDS-1,5-3-5.08_1x03_P5.08mm_Horizontal',
           'J1', 'OPENER', J1X, TY, lcsc='C474953')
J2 = place('TerminalBlock_Phoenix', 'TerminalBlock_Phoenix_MKDS-1,5-3-5.08_1x03_P5.08mm_Horizontal',
           'J2', 'SENSORS', J2X, TY, lcsc='C474953')
for p, n in ((1, 'RED'), (2, 'GND'), (3, 'BLACK')):
    connect(J1, p, n)
for p, n in ((1, 'CLOSED'), (2, 'OPEN'), (3, 'GND')):
    connect(J2, p, n)

# ---------------------------------------------------------------- send + receive (right of the XIAO)
SOT, R0603, C0603 = ('Package_TO_SOT_SMD', 'SOT-23'), ('Resistor_SMD', 'R_0603_1608Metric'), ('Capacitor_SMD', 'C_0603_1608Metric')
cx = 37.0
Q1 = place(*SOT, 'Q1', 'AO3400A', cx, 9.0, lcsc='C20917')
R1 = place(*R0603, 'R1', '10k', cx + 6.0, 9.0, 90, lcsc='C25804')
Q2 = place(*SOT, 'Q2', '2N7002', cx, 16.0, lcsc='C8545')
R2 = place(*R0603, 'R2', '10k', cx + 6.0, 16.0, 90, lcsc='C25804')
R3 = place(*R0603, 'R3', '1k', cx - 4.0, 19.5, 0, lcsc='C21190')
R4 = place(*R0603, 'R4', '100k', cx + 2.0, 19.5, 0, lcsc='C25803')
R5 = place(*R0603, 'R5', '10k', cx - 4.0, 24.0, 0, lcsc='C25804')
R6 = place(*R0603, 'R6', '10k', cx + 2.0, 24.0, 0, lcsc='C25804')
for fp, a, b in ((Q1, None, None),):
    pass
# AO3400A / 2N7002 SOT-23: 1 = G, 2 = S, 3 = D
connect(Q1, 1, 'TX'); connect(Q1, 2, 'GND'); connect(Q1, 3, 'RED')
connect(R1, 1, 'TX'); connect(R1, 2, 'GND')
connect(Q2, 1, 'RX_G'); connect(Q2, 2, 'GND'); connect(Q2, 3, 'RX')
connect(R2, 1, '+3V3'); connect(R2, 2, 'RX')
connect(R3, 1, 'RED'); connect(R3, 2, 'RX_G')
connect(R4, 1, 'RX_G'); connect(R4, 2, 'GND')
connect(R5, 1, 'BLACK'); connect(R5, 2, 'OBST')
connect(R6, 1, 'OBST'); connect(R6, 2, 'GND')

# ---------------------------------------------------------------- sensor inputs
R9 = place(*R0603, 'R9', '1k', cx - 4.0, 28.0, 0, lcsc='C21190')
R7 = place(*R0603, 'R7', '10k', cx + 2.0, 28.0, 0, lcsc='C25804')
C1 = place(*C0603, 'C1', '100nF', cx + 7.0, 28.0, 0, lcsc='C14663')
R10 = place(*R0603, 'R10', '1k', cx - 4.0, 31.5, 0, lcsc='C21190')
R8 = place(*R0603, 'R8', '10k', cx + 2.0, 31.5, 0, lcsc='C25804')
C2 = place(*C0603, 'C2', '100nF', cx + 7.0, 31.5, 0, lcsc='C14663')
C3 = place(*C0603, 'C3', '100nF', cx + 7.0, 22.0, 90, lcsc='C14663')
connect(R9, 1, 'CLOSED'); connect(R9, 2, 'CLOSED_IN')
connect(R7, 1, 'CLOSED_IN'); connect(R7, 2, '+3V3')
connect(C1, 1, 'CLOSED_IN'); connect(C1, 2, 'GND')
connect(R10, 1, 'OPEN'); connect(R10, 2, 'OPEN_IN')
connect(R8, 1, 'OPEN_IN'); connect(R8, 2, '+3V3')
connect(C2, 1, 'OPEN_IN'); connect(C2, 2, 'GND')
connect(C3, 1, '+3V3'); connect(C3, 2, 'GND')
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
